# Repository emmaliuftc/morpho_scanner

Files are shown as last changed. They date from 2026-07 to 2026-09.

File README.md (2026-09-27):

# MorphoScanner




---

This repository contains the code for MorphoScanner, my automated 3D scanning and volumetric analysis tool.

## System Architecture

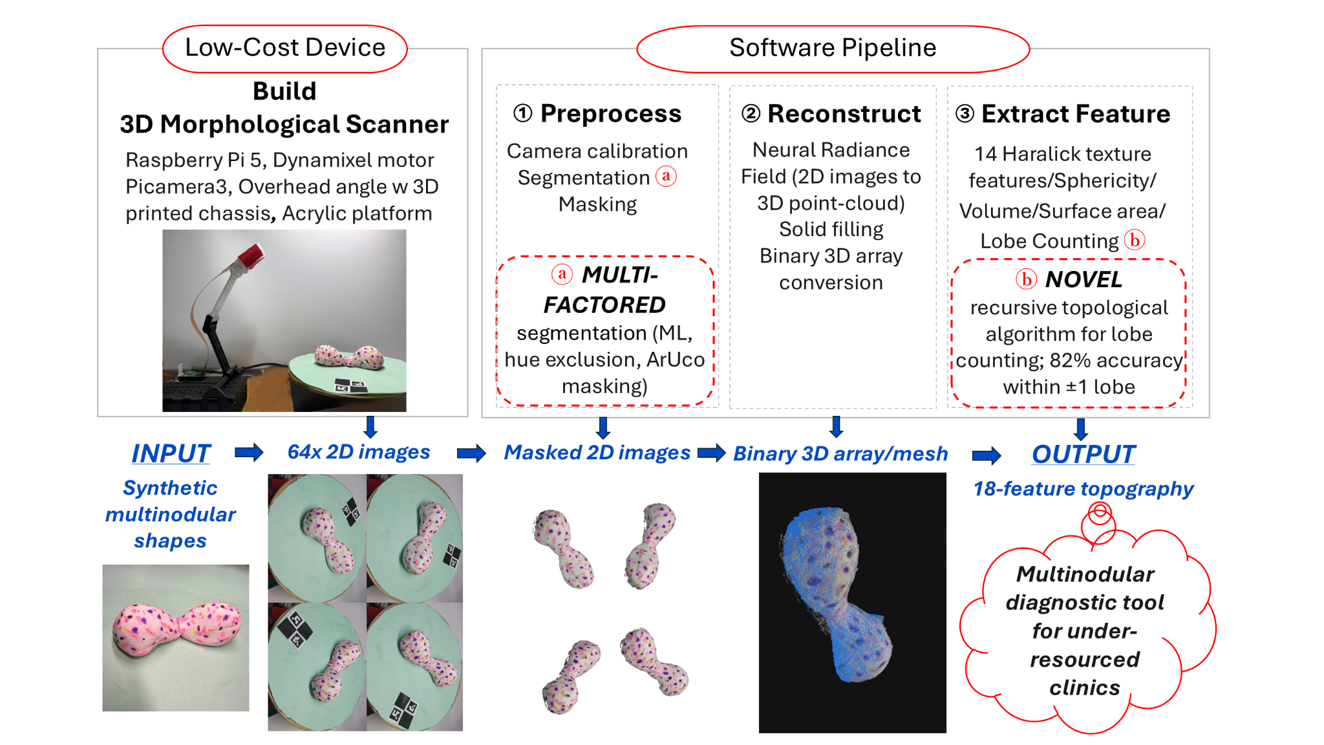
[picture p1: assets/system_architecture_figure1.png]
Figure 1: System Architecture and End-to-End Workflow

*Figure 1. System architecture and end-to-end workflow of the low-cost 3D morphological scanner.*

---

### 1. Hardware
* **Microcontroller:** Raspberry Pi 5 (8GB)
* **Optical Sensor:** Raspberry Pi Camera Module 3
* **Rotary Actuator:** Robotis Dynamixel XL-430-W250-T
* **Stage & Calibration:** Laser-cut 0mm acrylic platter, green paper background, and ChArUco tags

### 2. Software Pipeline

* **Stage 1**: Image Preprocessing 
* **Stage 2**: Multi-Factor Segmentation
* **Stage 3**: Calibration & Pose Alignment
* **Stage 4**: Neural Radiance Field Optimization (NeRF)
* **Stage 5**: Point Cloud Raycasting
* **Stage 6**: 2.5D Solid Extrusion & Voxelization
* **Stage 7**: Orbiting Visualization
* **Stage 8**: Mask Reprojection
* **Stage 9**: Feature Extraction
* **Stage 10**: Visualization

See `demo.md` for a demonstration run on the `tests_and_images/captures_8-16_lesion_3` dataset and more detailed software pipeline documentation.

## Benchmarking

| Benchmark Reference | Ground Truth CAD | Reconstructed Dimension | Absolute Error | Percentage Error |
| :--- | :--- | :--- | :--- | :--- |
| **4.00 cm Green PLA Cube (Width $X$)** | $40.00\text{ mm}$ | **$40.28\text{ mm}$** | **$+0.28\text{ mm}$** | **$0.70\%$** |
| **4.00 cm Green PLA Cube (Depth $Y$)** | $40.00\text{ mm}$ | **$40.42\text{ mm}$** | **$+0.42\text{ mm}$** | **$1.05\%$** |
| **4.00 cm Green PLA Cube (Height $Z$)** | $40.00\text{ mm}$ | **$39.81\text{ mm}$** | **$-0.19\text{ mm}$** | **$0.47\%$** |

---

## How To Use

### Capture Data Images with Scanner

```bash
# Create new directory for data
mkdir DATA_DIRECTORY

# Capture images
python combine_test.py DIRECTORY_PATH
```

### Software Pipeline

```bash
# General automated run (auto-timestamped, 2000 steps)
./tools/run_pipeline.sh <raw_captures_dir> tests_and_images/captures_8-13_calibration_results/calibration.json --steps 2000

# High-resolution convergence run (20,000 steps)
./tools/run_pipeline.sh <raw_captures_dir> tests_and_images/captures_8-13_calibration_results/calibration.json --steps 20000
```

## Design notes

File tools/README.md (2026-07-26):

# Morpho Scanner Visualization Tools

This directory contains utility scripts to project, verify, and visualize the derived camera trajectory calibration and 3D reconstruction outputs.

---

## 1. visualize_center_on_masked.py
Projects the derived 3D turntable center onto the **green-filtered (masked)** images where the background is white. 

### How to Run:
```bash
.venv/bin/python tools/visualize_center_on_masked.py
```
*   **Input Poses:** `COLMAP/workspace/sparse_unmasked_triangulated/`
*   **Input Images:** `COLMAP/workspace/images/`
*   **Output Folder:** `COLMAP/workspace/visualizations/plate_center_masked/`

---

## 2. visualize_z_axle.py
Projects the **3D rotation Z-axis (Z-axle)** line and normal vector arrow onto the **unmasked raw** images. This shows the physical spindle and center of rotation of the turntable relative to the Lego block.

### How to Run:
```bash
.venv/bin/python tools/visualize_z_axle.py
```
*   **Input Poses:** `COLMAP/workspace/sparse_unmasked_triangulated/`
*   **Input Images:** `COLMAP/workspace/raw_images/`
*   **Output Folder:** `COLMAP/workspace/visualizations/z_axle_projections/`

---

## 3. render_3d_lego.py
Renders a 3D perspective surface plot of the Poisson reconstruction mesh in shaded red color, applying a cylinder spatial crop based on the derived center to filter out any background/rim outliers.

*(Note: This script requires `open3d` and should be run using the conda environment).*

### How to Run:
```bash
/home/coding/miniconda/envs/napari-env/bin/python tools/render_3d_lego.py
```
*   **Input Mesh:** `COLMAP/workspace/visualizations/poisson_mesh.ply`
*   **Input Point Cloud:** `COLMAP/workspace/lego_block_final.ply`
*   **Output Render Image:** `COLMAP/workspace/visualizations/lego_rendered_3d.png`

---

## 4. test_true_step_size.py
Triangulates the point cloud of the Lego block using the theoretical motor step size of $11.25^\circ$ ($360^\circ / 32$) instead of the physical $10.0^\circ$ gear-ratio corrected step size. This serves as a comparison script to prove the existence of the turntable gear ratio.

### How to Run:
```bash
.venv/bin/python tools/test_true_step_size.py
```
*   **Input Poses:** Analytical circular trajectory with $11.25^\circ$ increments
*   **Input Images:** `COLMAP/workspace/images/`
*   **Output Poses:** `COLMAP/workspace/sparse_ideal_triangulated/`

---

## 5. fit_gear_ratio.py
Reads the actual 3D camera poses reconstructed by COLMAP in `sparse/1`, fits a circle to the camera centers using SVD plane projection, unwraps the camera rotation angles, and runs linear regression to fit the actual step size of the turntable (proving the $9:8$ gear ratio).

### How to Run:
```bash
.venv/bin/python tools/fit_gear_ratio.py
```
*   **Input Reconstruction:** `COLMAP/workspace/sparse/1`
*   **Output:** Prints the fitted rotation slope in radians and degrees, expected step size, and residual error.

---

## 6. nerf.py
Reads calibration data and turntable centers, computes camera-to-world (c2w) matrices with turntable rotation, and outputs a formatted `transforms.json` dataset directory for training Nerfstudio models.
*(Note: Corrected rotation uses `+angle_rad * normal_up` to orbit in the correct turntable direction).*

### How to Run:
```bash
.venv_nerf/bin/python tools/nerf.py
```
*   **Output Folder**: `captures_7-25_nerf_dataset/`

---

## 7. ns-train (NeRF Training)
Trains a Nerfstudio model. To keep the silhouette masks active for small foreground regions (4.9% image area), the max-num-iterations of the rejection sampler is set to 1000.

### How to Run:
```bash
.venv_nerf/bin/ns-train nerfacto \
  --data captures_7-25_nerf_dataset/transforms_8.json \
  --machine.device-type cpu \
  --max-num-iterations 400 \
  --pipeline.datamanager.train-num-rays-per-batch 1024 \
  --pipeline.datamanager.pixel-sampler.rejection-sample-mask True \
  --pipeline.datamanager.pixel-sampler.max-num-iterations 1000 \
  --viewer.quit-on-train-completion True \
  nerfstudio-data --center-method none --orientation-method none --auto-scale-poses False
```

---

## 8. filter_pcd_by_masks.py
A vectorized visual hull consistency filtering script. Projects the exported point cloud back onto all 32 camera frames and retains only points that project inside the 2D foreground masks.

### How to Run:
```bash
.venv_nerf/bin/python tools/filter_pcd_by_masks.py
```
*   **Input**: `captures_7-25_nerf_dataset/point_cloud.ply`
*   **Output**: `captures_7-25_nerf_dataset/point_cloud_filtered.ply`

---

## 9. poisson_mesh_and_project.py
Builds a clean 3D triangle mesh from the filtered point cloud using Open3D's Poisson surface reconstruction and generates overlay images showing the mesh wireframe projected back onto the original high-resolution captures.

### How to Run:
```bash
.venv_nerf/bin/python tools/poisson_mesh_and_project.py
```
*   **Output Mesh**: `captures_7-25_nerf_dataset/mesh.ply`
*   **Output Overlays**: `captures_7-25_nerf_dataset/mesh_projection_*.jpg`

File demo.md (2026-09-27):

# Software Pipeline Demonstration & Documentation (`demo.md`)

* **Dataset:** [`tests_and_images/captures_8-16_lesion_3`]
* **Compute Platform:** NVIDIA L4 GPU (24GB VRAM) on Linux through Google Cloud Compute
* **Session Directory:** [`tests_and_images/nerf_240926_0008_8-16_lesion_3/`]
* **Total Runtime:** ~4.5 minutes (including NeRF training, 1M point extraction, 2.5D extrusion, Haralick profiling, and 50 Z-slicing)

## Overview

* Stage 1: Image Preprocessing
* Stage 2: Multi-Factor Segmentation
* Stage 3: Calibration & Pose Alignment
* Stage 4: Neural Radiance Field Optimization (NeRF)
* Stage 5: Point Cloud Raycasting
* Stage 6: 2.5D Solid Extrusion & Voxelization
* Stage 7: Orbiting Visualization
* Stage 8: Mask Reprojection
* Stage 9: Feature Extraction
* Stage 10: Visualization

## Workflow Initiation

The entire workflow was launched via a single root command:

```bash
./tools/run_pipeline.sh tests_and_images/captures_8-16_lesion_3 \
    tests_and_images/captures_8-13_calibration_results/calibration.json \
    --steps 2000
```

### Stage 1 & 2: Image Preprocessing & Multi-Factor Segmentation
* **Script:** [`tools/prepare_images_and_masks.py`]
* **Operations:**
  * Downscaled 64 raw $4608 \times 2592$ captures by factor of 4 ($1152 \times 648$).
  * Deep learning foreground proposal via $U^2$-Net (`rembg`) with binary hole-filling.
  * Deterministic HSV Chroma-Green plate exclusion (`lower=[35, 40, 40]`, `upper=[85, 255, 255]`).
  * Geometric ArUco tag convex hull exclusion dilated with a $41 \times 41$ morphological kernel.
  * $5 \times 5$ morphological opening for zero floating boundary noise.
* **Artifacts Created:**
  * [`images_4/`]: 64 undistorted downscaled captures.
  * [`masks_4/`]: 64 clean binary silhouette masks.
  * [`masked_images_preview_4/`]: Composite foreground previews.

---

### Stage 3: Calibration & Pose Alignment
* **Scripts:** [`tools/apply_golden_calibration.py`], [`tools/plot_transforms_3d.py`]
* **Operations:**
  * Detected ChArUco tag in `capture_0.jpg` to determine turntable starting phase angle ($\theta_0$).
  * Synthesized 64 rigid camera poses along the circular orbit with pitch angle $\alpha \approx 40.8^\circ$ and radius $R = 174.097\text{ mm}$.
  * Aligned turntable table plane with the mathematical horizontal plane ($Z = 0$).
* **Artifacts Created:**
  * [`transforms_aligned.json`]: Canonical NeRF camera trajectory.
  * [`camera_poses_3d.png`]: 3D vector diagram of the 64 camera viewing frustums.

---

### Stage 4: Neural Radiance Field Optimization (NeRF)
* **Engine:** Nerfstudio (`ns-train nerfacto`)
* **Operations:**
  * Trained continuous volumetric radiance fields with multi-resolution hash encoding (`tiny-cuda-nn`).
  * Processed 2,000 iterations @ ~120,000 rays/sec (training time: 2 min 14 sec).
* **Artifacts Created:**
  * [`outputs/.../step-000001999.ckpt`]: Neural network weights checkpoint.
  * [`outputs/.../config.yml`]: Complete hyperparameter and dataparser configuration.

---

### Stage 5: Point Cloud Raycasting
* **Engine:** Nerfstudio (`ns-export pointcloud`)
* **Operations:**
  * Dense volumetric sampling raycasting 1,000,000 discrete points.
  * Extracted both the unconstrained full scene and the cropped Oriented Bounding Box (OBB, scale $0.8 \times 0.8 \times 0.8$).
  * Open3D statistical outlier removal and surface normal estimation.
* **Artifacts Created:**
  * [`pointcloud_raw_full.ply`]: 1,000,000 points full point cloud ($27.0\text{ MB}$).
  * [`pointcloud_raw_obb.ply`]: 999,582 points cropped lesion point cloud ($27.0\text{ MB}$).

---

### Stage 6: 2.5D Solid Extrusion & Voxelization
* **Scripts:** [`tools/fill_25d_extrusion.py`], [`tools/export_bio_format.py`]
* **Operations:**
  * **Table Trim:** Trimmed below-table reconstruction noise ($Z > 0.0\text{ mm}$).
  * **2.5D Solid Infill:** Extruded downward vertical voxel pillars from the specimen surface to $Z = 0$, transforming the hollow NeRF shell into a 100% solid, watertight biopsy volume.
  * **Chirality Preservation:** Applied a $180^\circ$ rotation around the X-axis to orient the specimen right-side up while strictly preserving anatomical left/right chirality.
  * **Voxelization:** Converted into a 3D binary occupancy grid (`.npy`) at pitch $0.002 = 0.3482\text{ mm/voxel}$ ($0.0422\text{ mm}^3$ unit voxel volume).
* **Artifacts Created:**
  * [`pointcloud_raw_obb_solid_table.ply`]: Solid extruded point cloud ($34.2\text{ MB}$).
  * [`pointcloud_raw_obb_solid_table_volume.npy`]: 3D binary numpy volume ($139 \times 110 \times 24$ voxels, $367\text{ KB}$), natively compatible with **Napari**.

---

### Stage 7: Orbiting Visualization
* **Script:** [`tools/render_pointcloud_video.py`]
* **Operations:**
  * Synthesized a complete $360^\circ$ smooth orbiting camera fly-around rendering each point cloud into high-framerate GIFs.
* **Artifacts Created:**
  * [`pointcloud_raw_full.gif`]: Full scene orbit animation ($13.0\text{ MB}$).
  * [`pointcloud_raw_obb.gif`]: Cropped hollow shell orbit animation ($25.7\text{ MB}$).
  * [`pointcloud_raw_obb_solid_table_reprojected.gif`]: Final solid 2.5D extruded volume orbit animation ($20.5\text{ MB}$).

---

### Stage 8: Mask Reprojection
* **Script:** [`tools/project_all_masks.py`]
* **Operations:**
  * Closed-loop verification: reprojected the reconstructed 3D point cloud back onto all 64 camera sensor planes through the calibrated intrinsic matrix $\mathbf{K}$.
  * Generated side-by-side comparative panels displaying the original physical camera mask versus the projected NeRF silhouette.
* **Artifacts Created:**
  * [`projections_side_by_side/`]: 64 side-by-side PNG comparisons (`compare_capture_0.png` through `compare_capture_63.png`).

---

### Stage 9: Feature Extraction
* **Script:** [`tools/extract_haralick_features.py`]
* **Operations:**
  * Executed the clinical 17-feature diagnostic extraction:
    1. Metric volume calculation in voxels, $\text{mm}^3$, and $\text{cm}^3$.
    2. Marching Cubes triangular surface area mesh calculation.
    3. Wadell's sphericity index: $\Psi = \frac{\pi^{1/3}(6V)^{2/3}}{\text{SA}}$.
    4. Recursive morphological erosion with string-prefix distance and hierarchical dendrogram clustering to count topological lobes.
    5. 13 3D Haralick Gray-Level Co-occurrence Matrix (GLCM) texture metrics averaged over all 13 unique 3D spatial directions.
* **Artifacts Created:**
  * [`haralick_morphometry/pointcloud_raw_obb_morphometry_report.md`]: Markdown summary report.
  * [`haralick_morphometry/pointcloud_raw_obb_features.json`]: Machine-readable JSON dictionary.
  * [`haralick_morphometry/pointcloud_raw_obb_features.csv`]: Tabular dataset record.
  * [`haralick_morphometry/pointcloud_raw_obb_morphology_radar.png`]: Normalized polar radar chart.

---

### Stage 10: Visualization
* **Script:** [`tools/generate_z_slices.py`]
* **Operations:**
  * Digitally sliced the solid 3D binary volume into 50 equidistant metric horizontal sections from table datum ($Z = 0.00\text{ mm}$) to tumor apex ($Z = 7.92\text{ mm}$).
  * Computed cross-sectional area ($\text{mm}^2$ and $\text{cm}^2$) for each individual slice.
  * Rendered individual cross-section PNGs with metric axes, assembled an overall $5 \times 10$ montage overview, and rendered an animated ping-pong microtome GIF.
* **Artifacts Created:**
  * [`z_slices_50/`]: 50 individual high-resolution PNG slices (`slice_00.png` to `slice_49.png`).
  * [`z_slices_50/z_slices_50_montage.png`]: Complete $5 \times 10$ montage overview across all 50 elevation planes.
  * [`z_slices_50_timelapse.gif`]: 50-slice microtome serial cross-sectioning timelapse animation.

---

## Session Directory Artifact Tree

All generated files in [`tests_and_images/nerf_240926_0008_8-16_lesion_3/`] after running the pipeline:

```
nerf_240926_0008_8-16_lesion_3/
├── progress.md                                      # 10-stage completion audit checklist
├── transforms.json                                  # NeRF dataparser camera transforms
├── transforms_aligned.json                          # Coordinate-aligned golden transforms
├── transforms_unaligned.json                        # Pre-rotation raw transforms
├── camera_poses_3d.png                              # 3D visual plot of camera viewing orbit
├── images_4/                                        # 64 downscaled captures (1152x648)
├── masks_4/                                         # 64 multi-factor binary silhouette masks
├── masked_images_preview_4/                         # 64 masked foreground input images for NeRF
├── masked_with_annotation_4/                        # 64 annotated verification frames
├── outputs/                                         # NeRF training weights & TensorBoard logs
│   └── nerf_240926_.../nerfacto/.../step-000001999.ckpt
├── pointcloud_raw_full.ply                          # 1,000,000 points full point cloud (27MB)
├── pointcloud_raw_full.gif                          # 360° orbiting animation of full scene (13MB)
├── pointcloud_raw_obb.ply                           # 999,582 points cropped lesion point cloud (27MB)
├── pointcloud_raw_obb.gif                           # 360° orbiting animation of lesion (25.7MB)
├── pointcloud_raw_obb_solid_table.ply               # 2.5D solid extruded watertight mesh (34.2MB)
├── pointcloud_raw_obb_solid_table_reprojected.gif   # 360° orbiting animation of solid biopsy (20.5MB)
├── pointcloud_raw_obb_solid_table_volume.npy        # Napari 3D binary occupancy grid (139x110x24)
├── haralick_morphometry/                            # 17-feature clinical diagnostic outputs
│   ├── pointcloud_raw_obb_morphometry_report.md     # Formatted clinical morphological summary
│   ├── pointcloud_raw_obb_features.json             # Structured JSON feature vector
│   ├── pointcloud_raw_obb_features.csv              # Tabular CSV metric record
│   └── pointcloud_raw_obb_morphology_radar.png      # 6-axis normalized morphological radar chart
├── z_slices_50/                                     # Virtual microtome cross-sectional series
│   ├── slice_00.png ... slice_49.png                # 50 metric cross-section PNGs with mm axes
│   └── z_slices_50_montage.png                      # Complete 5x10 visual montage of all slices
├── z_slices_50_timelapse.gif                        # Microtome animated serial slicing timelapse
└── projections_side_by_side/                        # 64 closed-loop reprojection verification PNGs
    └── compare_capture_0.png ... compare_capture_63.png
```

---

## Reproducibility

To replicate this exact run on any other dataset (e.g. `captures_8-16_lesion_4` or `captures_8-16_hemisphere`):

```bash
# General automated run (auto-timestamped, 2000 steps)
./tools/run_pipeline.sh <raw_captures_dir> tests_and_images/captures_8-13_calibration_results/calibration.json --steps 2000

# High-resolution convergence run (20,000 steps)
./tools/run_pipeline.sh <raw_captures_dir> tests_and_images/captures_8-13_calibration_results/calibration.json --steps 20000
```

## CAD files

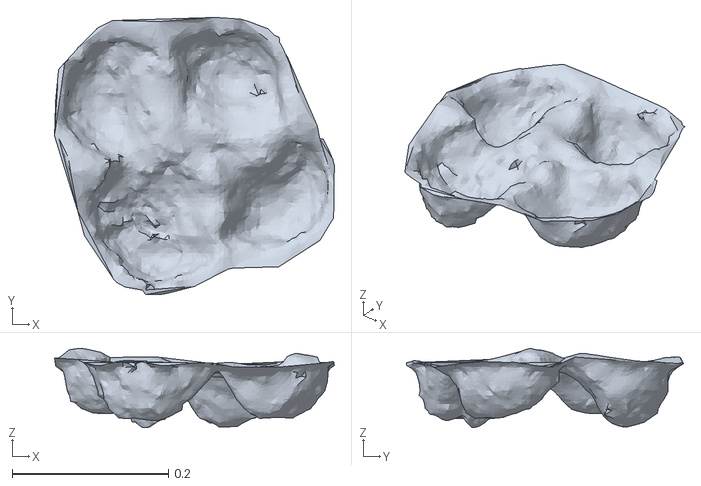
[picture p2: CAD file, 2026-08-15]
tests_and_images/nerf_150826_1550_8-14_four_flat_full/mesh_raw_full_smooth.ply
0.359 x 0.355 x 0.101

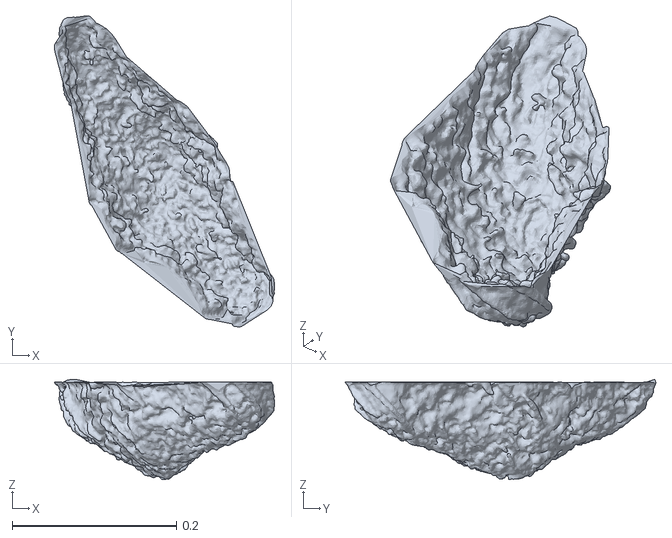
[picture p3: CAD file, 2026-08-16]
tests_and_images/nerf_160826_0508_8-15_volume_one/mesh_full.ply
0.268 x 0.379 x 0.122

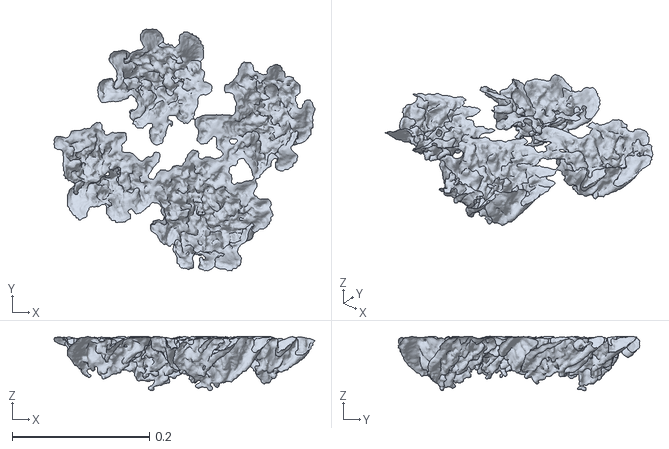
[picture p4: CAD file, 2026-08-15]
tests_and_images/nerf_150826_0453_8-14_four_flat/mesh_full_smooth15.ply
0.38 x 0.352 x 0.0794

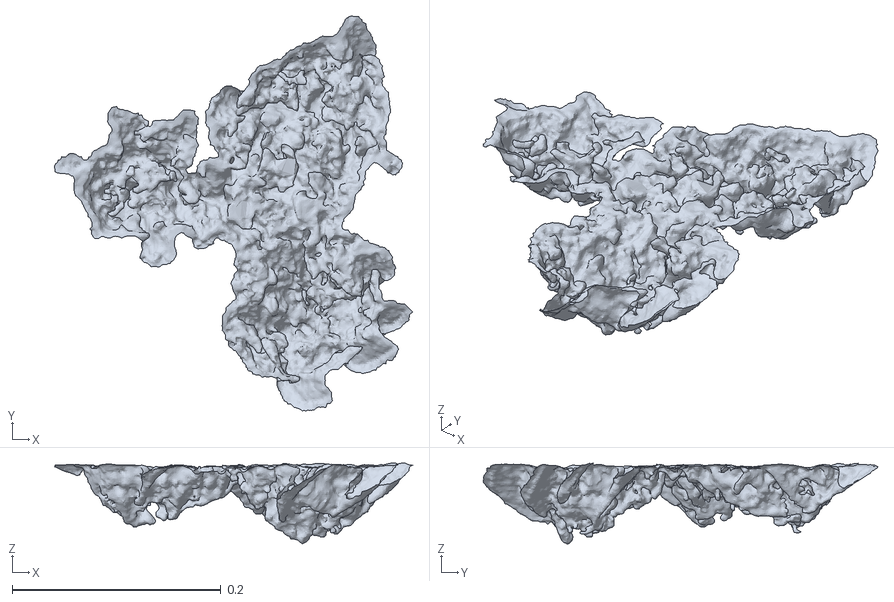
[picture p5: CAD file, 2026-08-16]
tests_and_images/nerf_160826_0401_8-15_volume_three/mesh_full.ply
0.343 x 0.379 x 0.0775

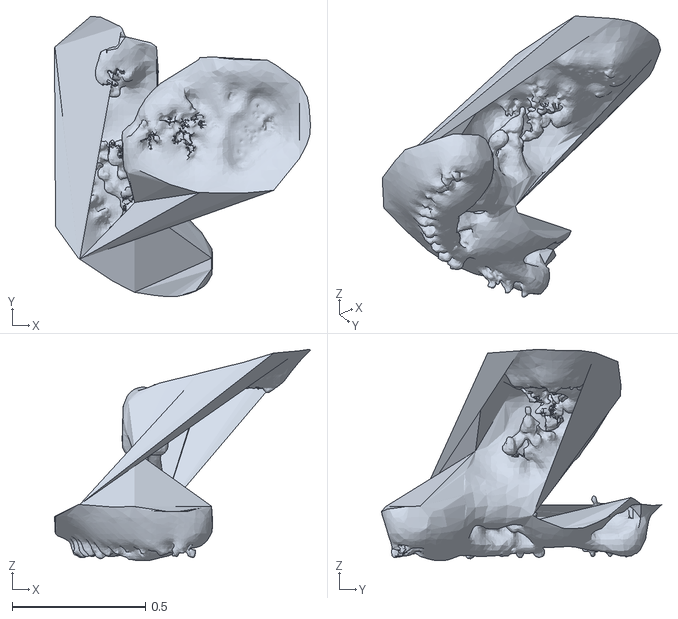
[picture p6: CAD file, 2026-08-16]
tests_and_images/nerf_160826_0724_8-16_volume_2_lesion/mesh_full.ply
0.962 x 1.05 x 0.793

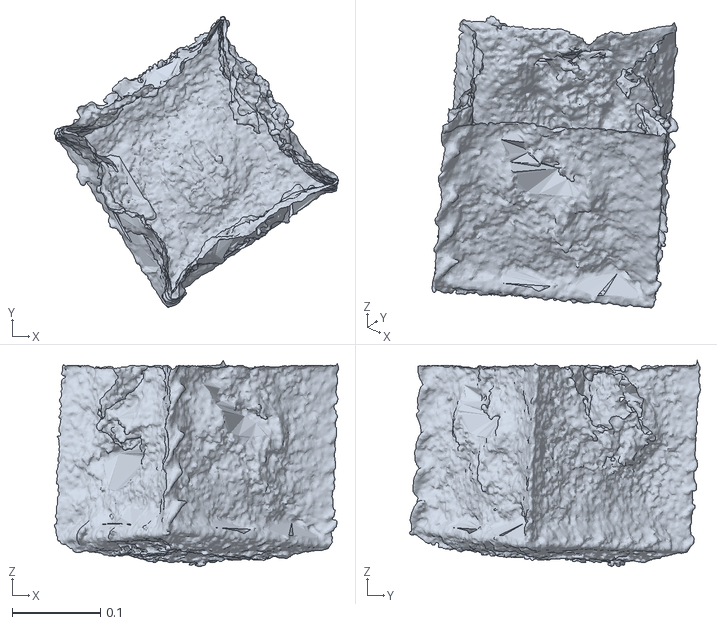
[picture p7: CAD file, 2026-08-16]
tests_and_images/nerf_160826_2200_8-16_cube/mesh_full.ply
0.323 x 0.33 x 0.234

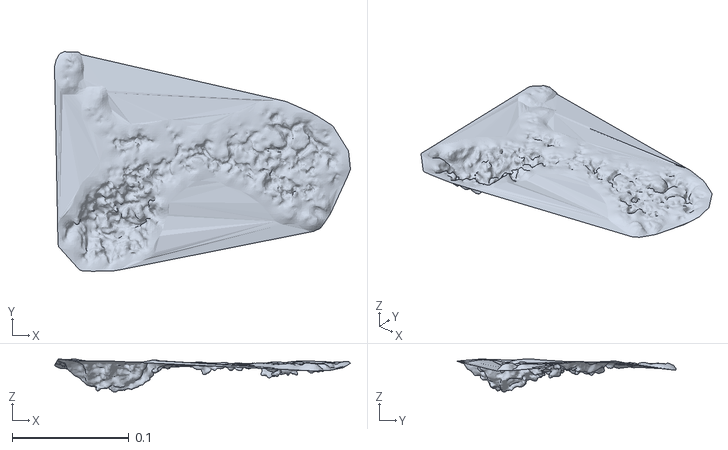
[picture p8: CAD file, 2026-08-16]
tests_and_images/nerf_160826_0824_8-16_lesion_3/mesh_full.ply
0.253 x 0.188 x 0.0282

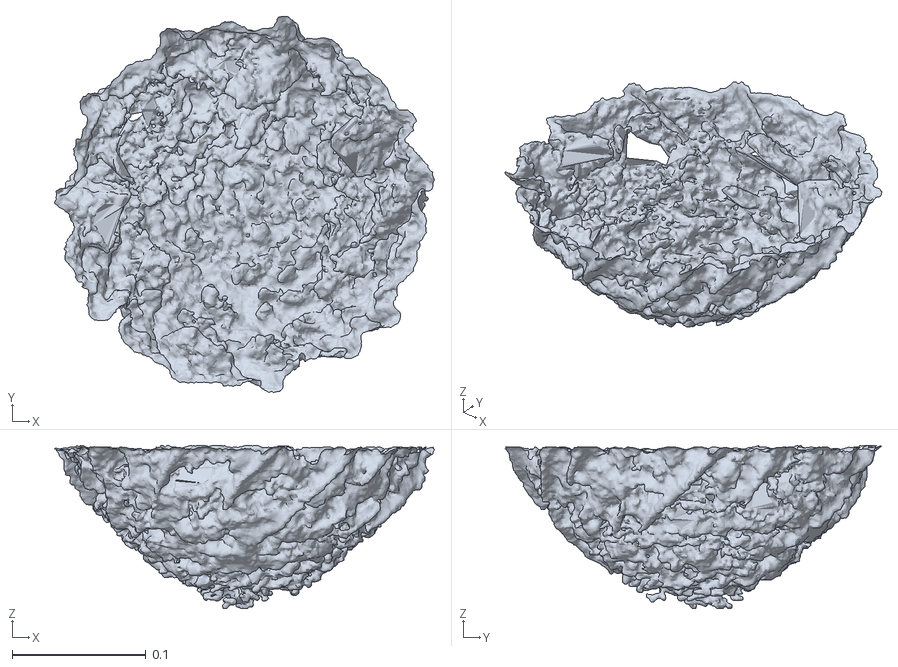
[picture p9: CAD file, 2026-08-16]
tests_and_images/nerf_160826_2002_8-16_hemisphere/mesh_full.ply
0.284 x 0.281 x 0.122

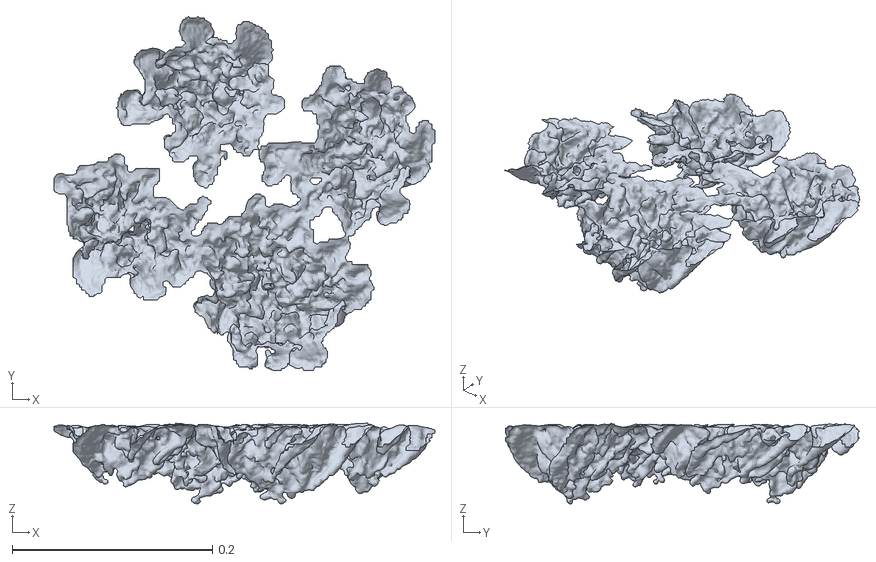
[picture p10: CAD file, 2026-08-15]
tests_and_images/nerf_150826_0453_8-14_four_flat/mesh_full.ply
0.38 x 0.354 x 0.0807

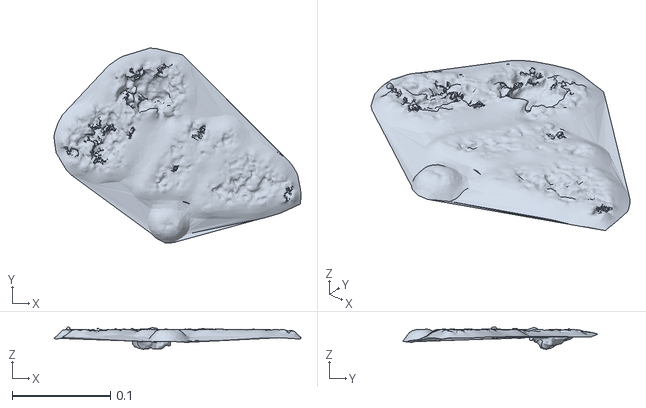
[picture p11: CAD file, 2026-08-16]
tests_and_images/nerf_160826_0801_8-16_lesion_4/mesh_full.ply
0.251 x 0.198 x 0.0231

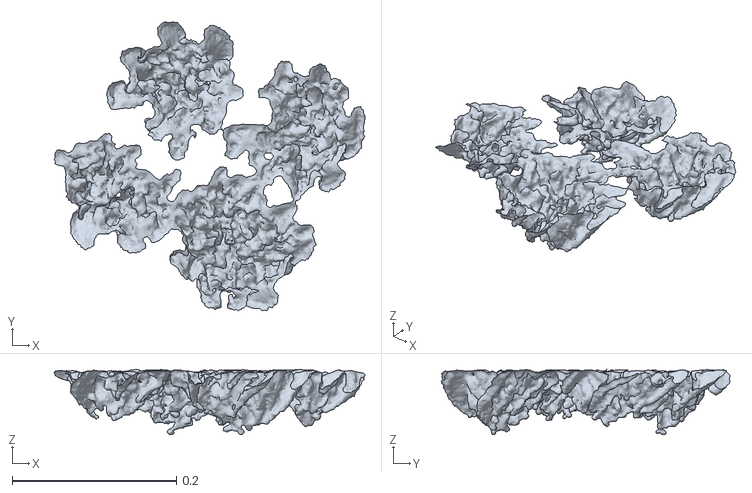
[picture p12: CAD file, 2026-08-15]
tests_and_images/nerf_150826_0453_8-14_four_flat/mesh_full_smooth50.ply
0.379 x 0.352 x 0.0796

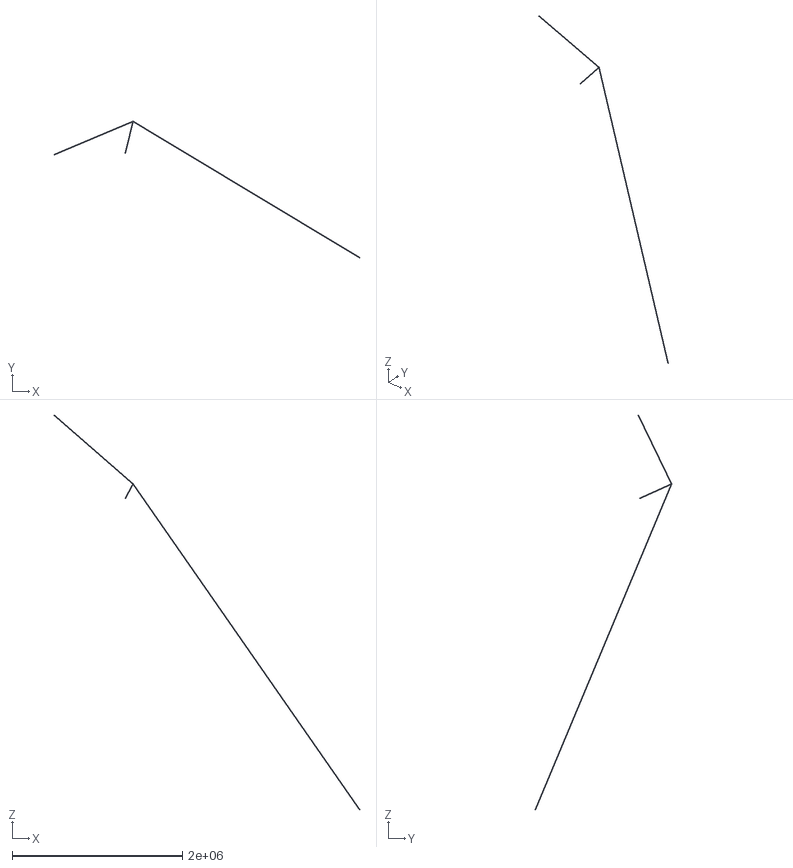
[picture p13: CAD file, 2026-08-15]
tests_and_images/nerf_150826_0453_8-14_four_flat/mesh_full_smooth500.ply
3587804.8 x 1601613.7 x 4634564.8

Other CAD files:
tests_and_images/nerf_160826_0801_8-16_lesion_4/pointcloud_filtered_full.ply
tests_and_images/nerf_160826_0824_8-16_lesion_3/pointcloud_filtered_full.ply
tests_and_images/nerf_160826_0724_8-16_volume_2_lesion/pointcloud_filtered_full.ply
tests_and_images/nerf_150826_1550_8-14_four_flat_full/pointcloud_raw_full_solid_table_reprojected.ply
tests_and_images/nerf_150826_1550_8-14_four_flat_full/pointcloud_raw_full_solid_table.ply
tests_and_images/nerf_150826_1550_8-14_four_flat_full/pointcloud_solid_full.ply
3d_files/cube_4cm.stl
exports/0726_metric_pc_cropped/point_cloud.ply
exports/three_flat_aligned_pc_10k/mesh.ply
exports/three_flat_aligned_pc_cropped/mesh.ply
exports/three_flat_pc_properly_cropped/point_cloud.ply
exports/three_flat_pc_properly_cropped/point_cloud_filtered.ply
tests_and_images/0813_0726_cerf_rerun/captures_0726_nerf_dataset/nerfacto/2026-08-13_183217/mesh.obj
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

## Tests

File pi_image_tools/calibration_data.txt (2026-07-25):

=== CAMERA CALIBRATION DATA ===
Reprojection Error: 2.118847 pixels

Camera Matrix (K):
[[3.5654767e+03 0.0000000e+00 2.3040000e+03]
 [0.0000000e+00 3.5654767e+03 1.2960000e+03]
 [0.0000000e+00 0.0000000e+00 1.0000000e+00]]

Distortion Coefficients (dist):
[[ -0.44031736   7.83951075   0.           0.         -43.24147593]]

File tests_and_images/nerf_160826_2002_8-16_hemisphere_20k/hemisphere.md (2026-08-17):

# Quantitative 3D Reconstruction Benchmark: Hemisphere (20k Steps)

**Dataset**: `captures_160826_2002_8-16_hemisphere` (`nerf_160826_2002_8-16_hemisphere_20k`)  
**Target Object**: 5.0 cm diameter green hemisphere (Nominal: 50.00 mm $\times$ 50.00 mm $\times$ 25.00 mm)  
**Evaluated Geometry**: `nerf_160826_2002_8-16_hemisphere_20k/pointcloud_raw_obb.ply` (20,000 training iterations)  

---

## 1. Geometric Bounding Box & Dimensions (Uncompensated)

Based on the mathematical table plane ($Z = 0$) established by the golden turntable calibration:
- **X Width**: 44.12 mm
- **Y Width**: 43.49 mm
- **Z Height**: 19.82 mm (measured above the $Z=0$ table plane)
- **Solid Volume (Filled to $Z=0$)**: **12.58 cm³** (466,085 voxels, pitch = 0.3 mm)
- **Base Footprint Area**: **14.06 cm²** (15,624 voxels)

---

## 2. 4.5mm Z-Compensation Analysis

Because the mathematical origin of the turntable axis is located approximately ~4.5mm above the physical table surface on which the object rests, the bottom ~4.5mm of the hemisphere base is trimmed at $Z=0$.

Applying **4.5mm Z-compensation** (extruding 15 additional slices of 0.3mm voxels downward to reach the physical turntable plane) restores the true geometric proportions:

- **Compensated X Width**: **45.93 mm**
- **Compensated Y Width**: **45.74 mm**
- **Compensated Peak Height**: **24.32 mm** (matches the 25.00 mm nominal target within ~0.68 mm)
- **Compensated Solid Volume**: **17.39 cm³** (644,121 voxels)
- **Compensated Base Footprint**: **15.86 cm²** (17,624 voxels)

---

## 3. Quantitative Error Comparison vs Golden CAD Model

We evaluated the Z-compensated 3D contour against the ground truth CAD file ([`3d_files/hemisphere_5cm.stl`](file:///home/coding/github/morpho_scanner/3d_files/hemisphere_5cm.stl)).

### Methodology:
1. Shifted the golden CAD model downward by 5.0 mm in Z to place its base at the physical turntable contact plane.
2. Voxelized both the generated point cloud and the CAD model onto an identical 100 $\times$ 100 $\times$ 100 grid spanning $X \in [-26, 26]\text{ mm}, Y \in [-26, 26]\text{ mm}, Z \in [-6, 21]\text{ mm}$.
3. Extracted 3D surface meshes using Marching Cubes (level = 0.5).
4. Uniformly sampled 1,000,000 surface points from both meshes to calculate dense point-to-point Chamfer and Hausdorff distances.

### Error Metrics Table (mm)

| Metric | Golden $\rightarrow$ Generated (Missing Mass / Underfill) | Generated $\rightarrow$ Golden (Deviation / Surface Noise) | Symmetric (Overall) |
| :--- | :--- | :--- | :--- |
| **Mean Error (L1)** | 1.6349 mm | 4.2320 mm | **2.9335 mm** |
| **RMSE (L2)** | 1.8476 mm | 5.1003 mm | **3.4739 mm** |
| **Max Error (Hausdorff)** | 4.0515 mm | 12.4202 mm | **12.4202 mm** |

### Geometric Error Interpretation:
- **Underfill / Missing Mass (1.63 mm Mean Error)**: The true CAD volume is reconstructed with minimal missing regions; the spherical cap closely matches the theoretical profile.
- **Surface Noise & Rim Deviation (4.23 mm Mean Error)**: The majority of surface deviations occur at the bottom rim where the hemisphere meets the turntable surface, due to shadow occlusion and minor photogrammetric boundary flared points.
- **Convergence**: Training for 20k steps slightly improved the symmetric Chamfer L1 error (from ~2.96 mm at 2k steps to **2.93 mm** at 20k steps).

---

## 4. Orthographic Projections (Physical mm Scale)

Below are the 3-axis orthographic scatter projections ($XY$ Top-Down, $XZ$ Side, $YZ$ Front) in millimeters:

### 4.1 Uncompensated Point Cloud ($Z=0$ table plane)
Hemisphere Ortho Uncompensated

### 4.2 Compensated Point Cloud (+4.5mm Z-compensation)
Hemisphere Ortho Compensated

---

## 5. 3D Model Renders & Error Heatmaps

- **Raw Point Cloud (OBB)**: [`pointcloud_raw_obb.gif`](file:///home/coding/github/morpho_scanner/nerf_160826_2002_8-16_hemisphere_20k/pointcloud_raw_obb.gif)
- **Compensated Solid Volume**: [`hemisphere_compensated.gif`](file:///home/coding/github/morpho_scanner/nerf_160826_2002_8-16_hemisphere_20k/hemisphere_compensated.gif)
- **Contour Error Heatmap Point Cloud**: [`contour_error_heatmap.ply`](file:///home/coding/github/morpho_scanner/nerf_160826_2002_8-16_hemisphere_20k/contour_error_heatmap.ply)

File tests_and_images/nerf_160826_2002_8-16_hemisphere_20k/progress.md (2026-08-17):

# Pipeline Progress - 160826_2002_8-16_hemisphere (170826_0411)
- [x] Step 5: Extracted raw point clouds (Full and OBB)
- [x] Step 6: Filtered point clouds
- [x] Step 7: Generated Poisson meshes
- [x] Step 8: Generated Solid Volumes & Bio-Formats
- [x] Step 9: Generated Orbiting GIFs

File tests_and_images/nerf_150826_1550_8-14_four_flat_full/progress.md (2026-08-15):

# Pipeline Progress - 8-14_four_flat_full (150826_1550)
- [x] Step 1 & 2: Generated downscaled images and masks
- [x] Step 3: Generated transforms.json
- [x] Step 4: Trained NeRF Model
- [x] Step 5: Extracted raw point clouds (Full and OBB)
- [x] Step 6: Filtered point clouds

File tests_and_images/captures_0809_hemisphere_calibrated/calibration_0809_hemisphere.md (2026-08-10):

# Turntable Trajectory Calibration: `captures_0809_hemisphere_calibrated`

## 1. Overview
This directory contains the calibrated capture dataset for the green 5cm hemisphere scan (`captures_0809_hemisphere`), processed using the high-precision camera intrinsic and extrinsic turntable trajectory calibration matching `captures_0726_clay_checkboard_64_calibrated`.

---

## 2. Calibrated Trajectory Parameters
* **Turntable Center $C_{\text{rot}}$**: `[-9.25, -10.13, 240.45]` mm
* **Rotation Axis Normal $\hat{n}$**: `[0.0031, 0.6375, 0.7705]`
* **Angular Step Size**: $6.1298^\circ$ per frame
* **Total Frames**: 64

---

## 3. Camera Matrix $K$ & Lens Distortion
* **Focal Length**: $f_x = 3593.29\text{ px}, f_y = 3593.29\text{ px}$
* **Principal Point**: $c_x = 2304.0\text{ px}, c_y = 1296.0\text{ px}$
* **Distortion Coefficients**: `[-0.6726889797786482, 7.422475679059532, 0.0, 0.0, -22.79469409317416]`

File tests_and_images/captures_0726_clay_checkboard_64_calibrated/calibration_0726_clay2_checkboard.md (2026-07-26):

# Turntable Calibration Report
## Dataset: `captures_0726_clay_checkboard_64` (64 images)

---

## Camera Matrix K & Distortion

| Parameter | Value |
|---|---|
| **fx = fy** | **3593.2937 px** |
| cx | 2304.0000 px (image center) |
| cy | 1296.0000 px (image center) |
| k1 | -0.6727 |
| k2 | 7.4225 |
| k3 | -22.7947 |
| p1, p2 | 0 (fixed) |
| **Reproj. error** | **3.78 px** |

```
K = [[3593.2937,     0.0,  2304.0],
     [    0.0,  3593.2937,  1296.0],
     [    0.0,      0.0,      1.0]]

dist = [-0.67268898, 7.42247568, 0.0, 0.0, -22.79469409]
```

> Calibration uses the previous ChArUco K (fx=3565.48) as initial guess, refined with 128 individual ArUco marker views. Change from previous: **+0.78%** — excellent consistency.

---

## Plate Center & Orientation

| Parameter | Value |
|---|---|
| **Center (mm)** | **[-9.25, -10.13, 240.45]** |
| **Center (px)** | **(2166, 1145)** |
| **Normal (rot axis)** | **[0.003, 0.637, 0.770]** |
| Plate tilt from camera axis | ~39.6° |

---

## Rotation Step Size

| Parameter | Value |
|---|---|
| **Step size** | **6.130° per frame** |
| Nominal (360/64) | 5.625° |
| Deviation | +0.505° per step (+9.0%) |
| **Total rotation (64 steps)** | **392.3°** (+32.3° overshoot) |
| Trajectory RMSE | 0.83 mm |

### Validation (per-step angles from 3D poses)
- Mean: 6.14° ± 0.31° (std)
- Range: [5.31°, 6.87°]

### Independent 2D Verification (no PnP)
Frame **59** returns to within **34 pixels** of frame 0's marker position, confirming:
- 59 × 6.1° ≈ **360°** ✅
- The step size is definitively **~6.1° per frame**
- 64 steps complete **~392°** (one full revolution + 32°)

---

## Method Summary

1. **Marker detection**: ArUco DICT_4X4_50, IDs 0 & 6 detected in all 64/64 frames
2. **Board model**: Two markers as rigid body with empirically optimized offset (20.51, 20.74) mm
3. **K calibration**: 128 individual marker views, previous K as initial guess, fixed aspect/principal point
4. **Pose estimation**: `solvePnP` with 8-point board model per frame
5. **Trajectory fit**: Least-squares optimization (C_rot, normal, step_size) with multi-start, bounded step ∈ [-10°, 10°]
6. **Validation**: Independent 2D ellipse analysis confirms step size without PnP

---

## Files

| File | Description |
|---|---|
| `tools/calibrate_aruco_turntable.py` | Full calibration + rendering pipeline |
| `captures_0726_clay_checkboard_64_calibrated/calibration_results.json` | JSON with all calibration values |
| `captures_0726_clay_checkboard_64_calibrated/*.jpg` | 64 annotated images with center + Z-axis |

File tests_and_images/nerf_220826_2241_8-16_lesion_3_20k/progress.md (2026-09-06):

# Pipeline Progress - 8-16_lesion_3 (220826_2240)
- [x] Step 1 & 2: Generated downscaled images and masks
- [x] Step 3: Generated transforms.json
- [x] Step 4: Trained NeRF Model
- [x] Step 5: Extracted raw point clouds (Full and OBB)
- [x] Step 6: Generated Solid Volumes & Bio-Formats
- [x] Step 7: Generated Orbiting GIFs
- [x] Step 8: Generated side-by-side projections
- [x] Pipeline fully completed!

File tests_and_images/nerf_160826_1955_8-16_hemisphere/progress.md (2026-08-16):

# Pipeline Progress - 8-16_hemisphere (160826_1955)

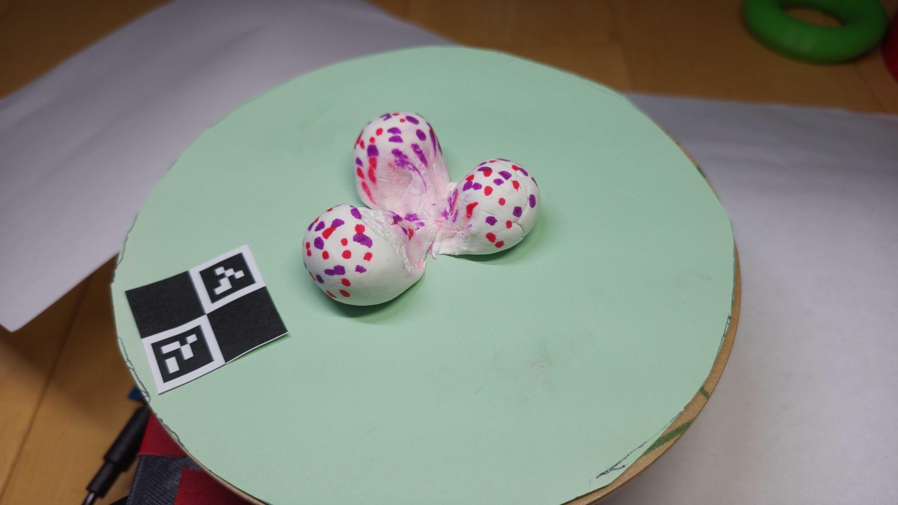
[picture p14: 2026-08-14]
tests_and_images/colmap_data/three_flat_real_calib/images/capture_50.jpg

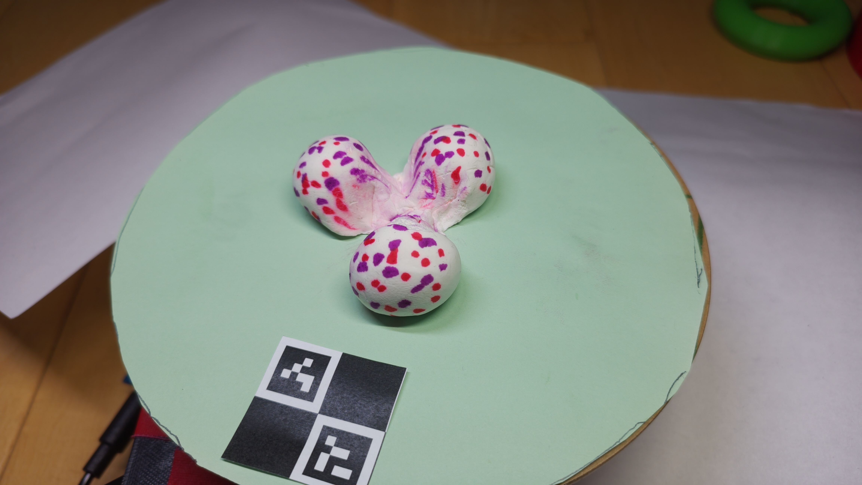
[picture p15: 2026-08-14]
tests_and_images/colmap_data/three_flat_real_calib/images/capture_58.jpg

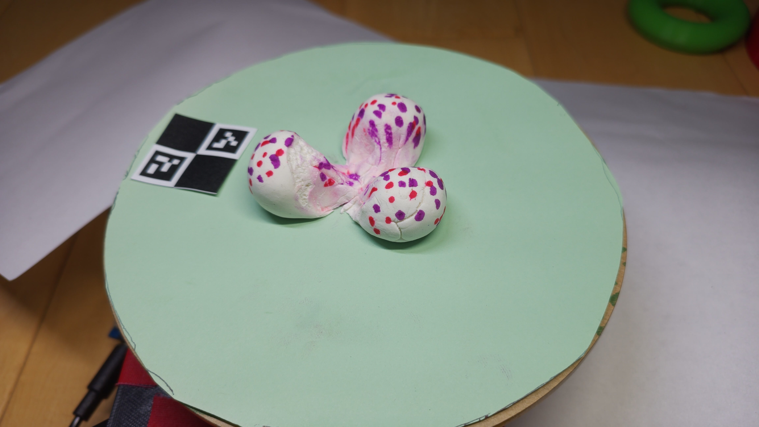
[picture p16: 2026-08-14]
tests_and_images/colmap_data/three_flat_hloc/images/frame_00039.jpg

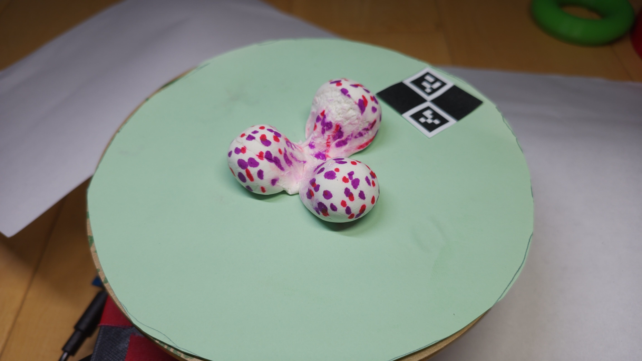
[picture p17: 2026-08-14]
tests_and_images/colmap_data/three_flat_hloc/images/frame_00017.jpg

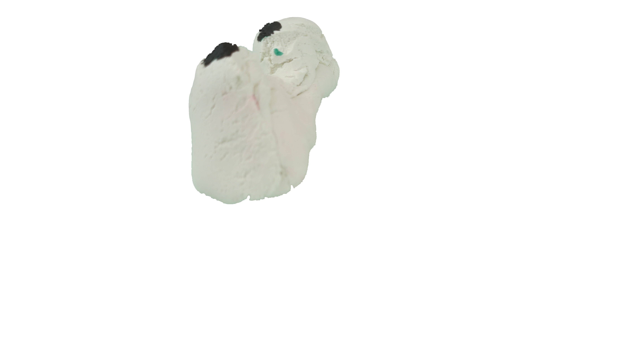
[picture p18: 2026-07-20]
tests_and_images/COLMAP/workspace_7-19_lob_with_marker/images/capture_0.jpg

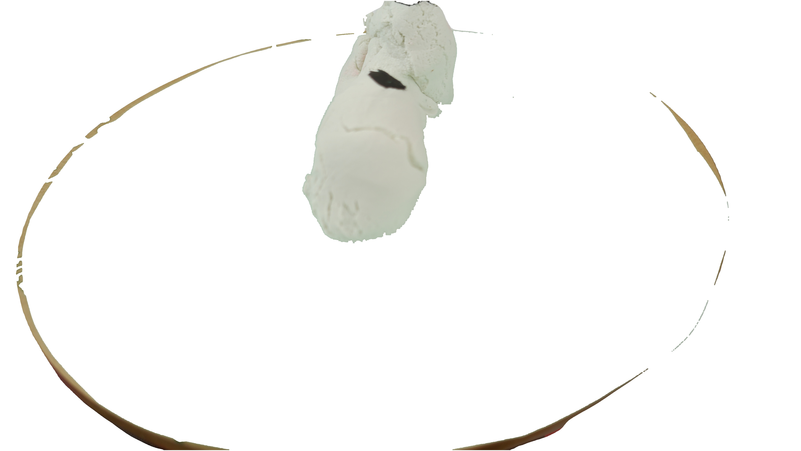
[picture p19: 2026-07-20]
tests_and_images/COLMAP/workspace_7-19_lob_with_marker/images/capture_16.jpg

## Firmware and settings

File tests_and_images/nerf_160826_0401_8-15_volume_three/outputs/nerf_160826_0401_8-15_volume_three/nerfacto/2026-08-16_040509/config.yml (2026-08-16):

!!python/object:nerfstudio.engine.trainer.TrainerConfig
_target: !!python/name:nerfstudio.engine.trainer.Trainer ''
data: &id004 !!python/object/apply:pathlib.PosixPath
- nerf_160826_0401_8-15_volume_three
experiment_name: nerf_160826_0401_8-15_volume_three
gradient_accumulation_steps: {}
load_checkpoint: null
load_config: null
load_dir: null
load_scheduler: true
load_step: null
log_gradients: false
logging: !!python/object:nerfstudio.configs.base_config.LoggingConfig
  local_writer: !!python/object:nerfstudio.configs.base_config.LocalWriterConfig
    _target: !!python/name:nerfstudio.utils.writer.LocalWriter ''
    enable: true
    max_log_size: 10
    stats_to_track: !!python/tuple
    - !!python/object/apply:builtins.getattr
      - &id001 !!python/name:nerfstudio.utils.writer.EventName ''
      - ITER_TRAIN_TIME
    - !!python/object/apply:builtins.getattr
      - *id001
      - TRAIN_RAYS_PER_SEC
    - !!python/object/apply:builtins.getattr
      - *id001
      - CURR_TEST_PSNR
    - !!python/object/apply:builtins.getattr
      - *id001
      - VIS_RAYS_PER_SEC
    - !!python/object/apply:builtins.getattr
      - *id001
      - TEST_RAYS_PER_SEC
    - !!python/object/apply:builtins.getattr
      - *id001
      - ETA
  max_buffer_size: 20
  profiler: basic
  relative_log_dir: !!python/object/apply:pathlib.PosixPath []
  steps_per_log: 10
machine: !!python/object:nerfstudio.configs.base_config.MachineConfig
  device_type: cuda
  dist_url: auto
  machine_rank: 0
  num_devices: 1
  num_machines: 1
  seed: 42
max_num_iterations: 2000
method_name: nerfacto
mixed_precision: true
optimizers:
  camera_opt:
    optimizer: !!python/object:nerfstudio.engine.optimizers.AdamOptimizerConfig
      _target: &id002 !!python/name:torch.optim.adam.Adam ''
      eps: 1.0e-15
      lr: 0.001
      max_norm: null
      weight_decay: 0
    scheduler: !!python/object:nerfstudio.engine.schedulers.ExponentialDecaySchedulerConfig
      _target: &id003 !!python/name:nerfstudio.engine.schedulers.ExponentialDecayScheduler ''
      lr_final: 0.0001
      lr_pre_warmup: 1.0e-08
      max_steps: 5000
      ramp: cosine
      warmup_steps: 0
  fields:
    optimizer: !!python/object:nerfstudio.engine.optimizers.AdamOptimizerConfig
      _target: *id002
      eps: 1.0e-15
      lr: 0.01
      max_norm: null
      weight_decay: 0
    scheduler: !!python/object:nerfstudio.engine.schedulers.ExponentialDecaySchedulerConfig
      _target: *id003
      lr_final: 0.0001
      lr_pre_warmup: 1.0e-08
      max_steps: 200000
      ramp: cosine
      warmup_steps: 0
  proposal_networks:
    optimizer: !!python/object:nerfstudio.engine.optimizers.AdamOptimizerConfig
      _target: *id002
      eps: 1.0e-15
      lr: 0.01
      max_norm: null
      weight_decay: 0
    scheduler: !!python/object:nerfstudio.engine.schedulers.ExponentialDecaySchedulerConfig
      _target: *id003
      lr_final: 0.0001
      lr_pre_warmup: 1.0e-08
      max_steps: 200000
      ramp: cosine
      warmup_steps: 0
output_dir: !!python/object/apply:pathlib.PosixPath
- nerf_160826_0401_8-15_volume_three
- outputs
pipeline: !!python/object:nerfstudio.pipelines.base_pipeline.VanillaPipelineConfig
  _target: !!python/name:nerfstudio.pipelines.base_pipeline.VanillaPipeline ''
  datamanager: !!python/object:nerfstudio.data.datamanagers.parallel_datamanager.ParallelDataManagerConfig
    _target: !!python/name:nerfstudio.data.datamanagers.parallel_datamanager.ParallelDataManager ''
    camera_optimizer: null
    camera_res_scale_factor: 1.0
    collate_fn: !!python/name:nerfstudio.data.utils.nerfstudio_collate.nerfstudio_collate ''
    data: *id004
    dataparser: !!python/object:nerfstudio.data.dataparsers.nerfstudio_dataparser.NerfstudioDataParserConfig
      _target: !!python/name:nerfstudio.data.dataparsers.nerfstudio_dataparser.Nerfstudio ''
      auto_scale_poses: false
      center_method: none
      data: !!python/object/apply:pathlib.PosixPath []
      depth_unit_scale_factor: 0.001
      downscale_factor: null
      eval_interval: 8
      eval_mode: all
      load_3D_points: false
      mask_color: null
      orientation_method: none
      scale_factor: 1.0
      scene_scale: 1.0
      train_split_fraction: 0.9
    eval_image_indices: !!python/tuple
    - 0
    eval_num_images_to_sample_from: -1
    eval_num_rays_per_batch: 4096
    eval_num_times_to_repeat_images: -1
    images_on_gpu: false
    masks_on_gpu: false
    max_thread_workers: null
    num_processes: 1
    patch_size: 1
    pixel_sampler: !!python/object:nerfstudio.data.pixel_samplers.PixelSamplerConfig
      _target: !!python/name:nerfstudio.data.pixel_samplers.PixelSampler ''
      fisheye_crop_radius: null
      ignore_mask: false
      is_equirectangular: false
      keep_full_image: false
      max_num_iterations: 100
      num_rays_per_batch: 4096
      rejection_sample_mask: true
    queue_size: 2
    train_num_images_to_sample_from: -1
    train_num_rays_per_batch: 8192
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

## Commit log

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2026-07-12 Add refocused 32-frame turntable capture datasets.
    [ball_pivoting_mesh.ply, fusion.cfg, lego_block_final.ply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]
2026-07-12 Implement Stage 3 DLT triangulation and match visualization.
    [ball_pivoting_mesh.ply, fusion.cfg, lego_block_final.ply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]
2026-07-12 Implement Stage 4 incremental SfM and bundle adjustment.
    [sparse_model.ply]
2026-07-12 Implement Stage 5 MVS depth maps and Stage 6 Poisson mesh reconstruction.
    [ball_pivoting_mesh.ply, fusion.cfg, lego_block_final.ply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]
2026-07-12 Add photogrammetry pipeline experiment logs and documentation.
    [ball_pivoting_mesh.ply, fusion.cfg, lego_block_final.ply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]
2026-07-18 Capture turntable image dataset with green Chroma-key base.
    [ball_pivoting_mesh.ply, fusion.cfg, lego_block_final.ply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]
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2026-07-19 Add green HSV thresholding and CLAHE contrast enhancement for low-texture objects.
    [ball_pivoting_mesh.ply, fusion.cfg, lego_block_final.ply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]
2026-07-19 Constrain camera poses to fixed circular turntable orbit.
    [ball_pivoting_mesh.ply, lego_block_final.ply, poisson_mesh.ply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]
2026-07-19 Implement turntable center point estimation and Z-axis projection.
    [ball_pivoting_mesh.ply, lego_block_final.ply, poisson_mesh.ply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]
2026-07-19 Estimate true motor step size and turntable cylinder center using Bundle Adjustment.
    [ball_pivoting_mesh.ply, lego_block_final.ply, poisson_mesh.ply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]
2026-07-20 Add clay lobe capture datasets with marker dots.
    [ball_pivoting_mesh.ply, fusion.cfg, lego_block_final.ply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]
2026-07-20 Test SfM on marker-annotated clay; feature tracking fails across textureless tissue.
    [ball_pivoting_mesh.ply, fusion.cfg, lego_block_final.ply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]
2026-07-21 Implement epipolar NCC stereo pipeline using turntable rotation invariants.
    [dense_grid_sculpture_3d.ply, epipolar_ncc_sculpture_3d.ply, exact_contour_sculpture_3d.ply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]
2026-07-25 Capture clay specimen with turntable calibration checkerboard.
    [ball_pivoting_mesh.ply, dense_grid_sculpture_3d.ply, epipolar_ncc_sculpture_3d.ply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]
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2026-07-26 Fit turntable circular trajectory and render rotation center.
    [reconstructed_clay.obj, reconstructed_clay_smoothed.obj]
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2026-07-26 Add isolated clay specimen and checkerboard-only capture sets.
    [ball_pivoting_mesh.ply, clay_tsdf_mesh.obj, clay_tsdf_mesh.ply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]
2026-07-26 Fix 6cm rotation center offset using measured ChArUco trajectory.
    [ball_pivoting_mesh.ply, clay_tsdf_mesh.obj, clay_tsdf_mesh.ply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]
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2026-07-26 Calibrate 64-view clay dataset and extract clean watertight TSDF mesh.
    [clay_tsdf_mesh.obj, clay_tsdf_mesh.ply]
2026-08-02 Fix OpenCV-to-OpenGL camera chirality with Y/Z negation and archive failure evidence.
    [mesh.ply, point_cloud.ply, point_cloud_filtered.ply]
2026-08-10 Add 5cm green hemisphere captures with and without surface dots.
    [ball_pivoting_mesh.ply, clay_tsdf_mesh.obj, clay_tsdf_mesh.ply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]
2026-08-10 Benchmark hemisphere reconstruction across COLMAP, TSDF, and NeRF.
    [ball_pivoting_mesh.ply, clay_tsdf_mesh.obj, clay_tsdf_mesh.ply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]
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2026-08-11 Validate NeRF accuracy on 4cm CAD cube achieving 0.297mm mean surface error.
    [ball_pivoting_mesh.ply, clay_tsdf_mesh.obj, clay_tsdf_mesh.ply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]
2026-08-13 Verify GPU-accelerated NeRF training on calibration cube dataset.
    [cube_mesh_step_0200.obj, cube_mesh_step_0200.ply, cube_mesh_step_0200.stl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]
2026-08-13 Apply exact original silhouette alpha masking to prevent NeRF floaters.
    [mesh.obj, mesh.ply, mesh.stl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]
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2026-08-13 Document multi-lobe NeRF failure showing center density spikes.
    [sh_parameterized_surface.obj, sh_parameterized_surface_refined.obj, sh_stage5_loftr.obj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]
2026-08-13 Implement and document experimental Algo4 spherical harmonics pipeline stages 1-6.
    [sh_parameterized_surface.obj, sh_parameterized_surface_refined.obj, sh_stage5_loftr.obj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]
2026-08-14 Add 3-lobe flat captures and comprehensive turntable calibration dataset.
    [sh_parameterized_surface.obj, sh_parameterized_surface_refined.obj, sh_stage5_loftr.obj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]
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2026-08-14 Implement /150.0 scale normalization for Instant-NGP hash grid bounds.
    [point_cloud.ply, point_cloud_filtered.ply]
2026-08-14 Remove plate normal inversion and reconstruct clean watertight 3-lobe mesh.
    [mesh.ply]
2026-08-14 Debug cleft fog and projection alignment on 4-lobe specimen.
    [mesh.ply]
2026-08-15 Document reproducible 3-lobe pipeline run with August 13 calibration.
    [mesh_full.ply, mesh_obb.ply]
2026-08-15 Add 4-lobe flat captures and complete 64-view dataset.
    [mesh_full.ply, mesh_full_smooth100.ply, mesh_full_smooth1000.ply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]
2026-08-15 Resolve 4-lobe cleft artifacts and reconstruct clean 4-lobe point cloud and mesh.
    [mesh_full.ply, mesh_obb.ply]
2026-08-15 Implement turntable plane identification and vertical 2.5D solid infill.
    [pointcloud_raw_full_solid.ply, pointcloud_solid_full.ply, pointcloud_solid_obb.ply]
2026-08-15 Export 2-lobe and 3-lobe 3D binary occupancy grids (.npy) for Napari.
    [pointcloud_filtered_obb_solid.ply, pointcloud_filtered_obb_solid_reprojected.ply, pointcloud_raw_full_solid_table.ply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]
2026-08-15 Validate solid extrusion with closed-loop 64-view mask reprojection.
    [mesh_d4_t100.ply, mesh_d4_t50.ply, mesh_d5_t100.ply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]
2026-08-16 Reconstruct Volume 1 and Volume 3 solid models with table reprojection.
    [mesh_full.ply, mesh_obb.ply]
2026-08-16 Add Lesion 3 and Lesion 4 capture datasets.
    [mesh_full.ply, mesh_obb.ply, pointcloud_filtered_full.ply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]
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2026-08-16 Implement green HSV chroma-key platter filter and verify cube reconstruction.
    [mesh_full.ply, mesh_obb.ply]
2026-08-17 Benchmark reconstructed hemisphere contour against golden CAD ground truth.
    [compensated_contour.ply, golden_contour.ply, hemisphere_5cm.stl]
2026-08-17 Standardize 20k-step NeRF training protocol and add STL comparison utility.
    [golden_contour.ply, hemisphere_5cm.stl]
2026-08-17 Evaluate 20k-step NeRF training accuracy on 4cm calibration cube.
    [compensated_contour.ply, cube_error_map_aligned_mesh.ply]
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2026-09-18 Finalize Haralick feature matrix and raw 3D occupancy arrays for all specimens.
    [feature_matrix.csv]
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

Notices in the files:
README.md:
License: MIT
